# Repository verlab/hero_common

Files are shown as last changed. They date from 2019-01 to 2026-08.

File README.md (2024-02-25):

# HeRo: An Open Platform for Robotics Research and Education
<p align="justify">
Welcome to the HeRo project! This initiative introduces an innovative platform tailored for swarm robotics applications. It boasts affordability, ease of assembly using readily available components, and seamless integration with the industry-standard ROS (Robot Operating System). Our robotic platform is fully open-source, featuring a 3D-printed body coupled with open-source software. Within this repository, you'll discover a comprehensive range of ROS packages, firmware, simulations, examples, as well as additional resources such as CAD files, 3D models, schematics, and more.
</p>

For more in-depth information, please visit our documentation page [here](https://verlab.github.io/hero_common/).

<p align="center">
gif
</p>

## Authors
Paulo Rezeck (https://rezeck.github.io/)
Hector Azpurua (https://github.com/h3ct0r)
Maurício Ferrari (https://github.com/mauferrari)

## Contributing
We welcome and appreciate contributions from the community. If you have ideas, bug fixes, or enhancements you'd like to propose, please feel free to open an issue or submit a pull request. Together, we can make HeRo an even better platform for robotics enthusiasts and researchers.

Thank you 🙏 to all our contributors!

[vitorHoller](https://github.com/vitorHoller)
[Suptree](https://github.com/Suptree)
[CaioContiG](https://github.com/CaioContiG)

## License
<br />This work is licensed under a <a rel="license" href="http://creativecommons.org/licenses/by-nc-nd/4.0/">Creative Commons Attribution-NonCommercial-ShareALike 4.0 International License</a>.

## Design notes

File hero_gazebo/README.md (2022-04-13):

# Gazebo Simulations
We provide HeRo simulations on Gazebo.

## HeRo Wizard
We create a high-level UI interface that should help others to instantiate a gazebo environment.
Its is a simple wizard software that help select an environment and the robots. 
After selecting, and commit the object, they should appear on gazebo were we can drag them and place them wherever we want.
Finally, generate a launch file that compile this setup.

To create a environment, use this launch file:
```sh
$ roslaunch hero_gazebo gazebo_wizard.launch
```
It will open gazebo and this UI interface:

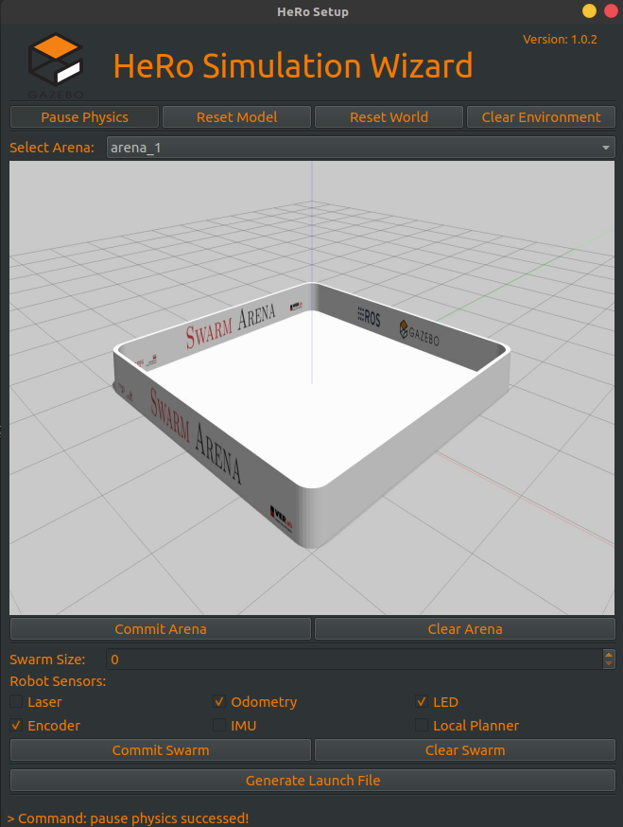
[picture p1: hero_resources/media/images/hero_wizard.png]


### Steps:

1. Select the arena in the list (see figure);
2. By clicking on commit arena button, the object will be instantiate on gazebo. Clear arena button should remove it.
3. Select the number of robots.
4. Select the sensors available for the robots.
5. By clicking on commit swarm button, the robots will be instantiate on gazebo. Clear swarm will remove them.
6. By using gazebo simulator, make adjustments on the scene, and using the Generate Launch File button will compile the scene in a launch file for future uses.

To launch a pre-set environment, use this launch file:
```sh
$ roslaunch hero_gazebo env_spawn.launch
```

## Features
- Differential drive controller
- Odometry
- IMU
- IR Proximity range (simulated with laser)

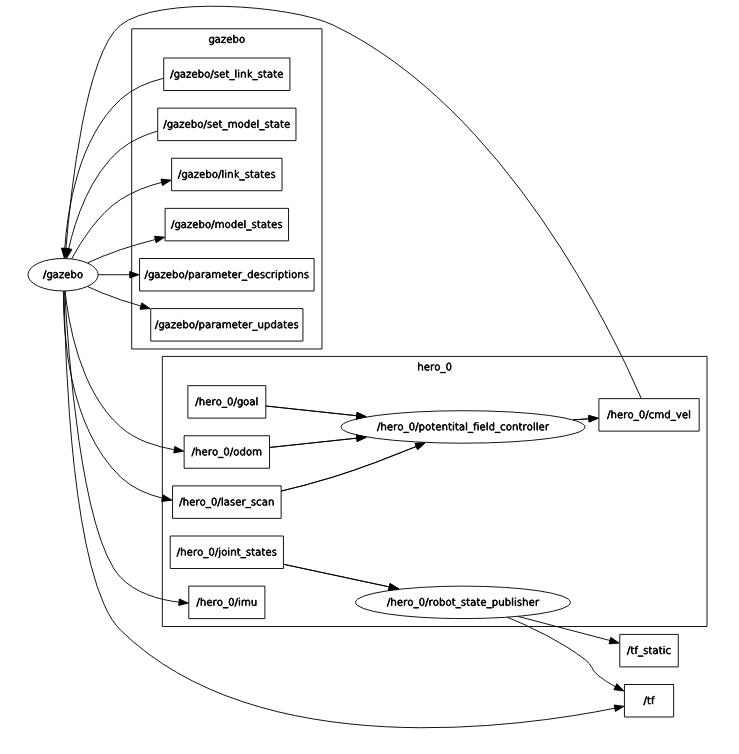
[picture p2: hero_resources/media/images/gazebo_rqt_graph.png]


## How to use
- Open the terminal and type the following command. This command will initiate Gazebo and spawn on HeRo using potential field controller as an example.
```sh
$ roslaunch hero_gazebo gazebo_bringup.launch 
```
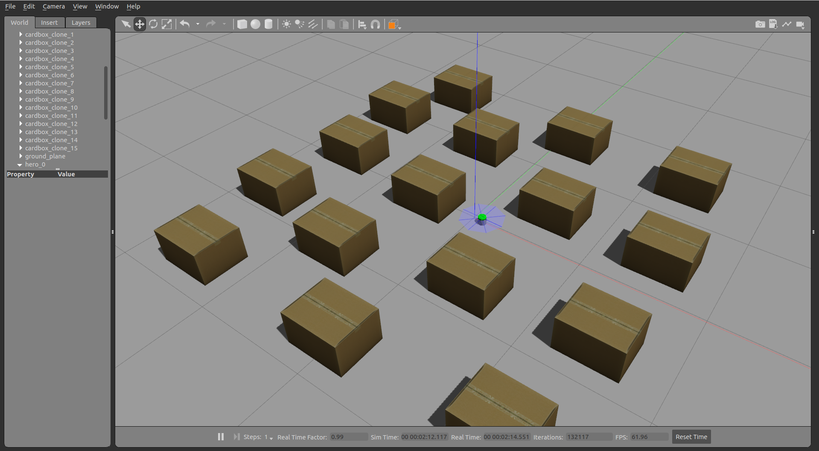
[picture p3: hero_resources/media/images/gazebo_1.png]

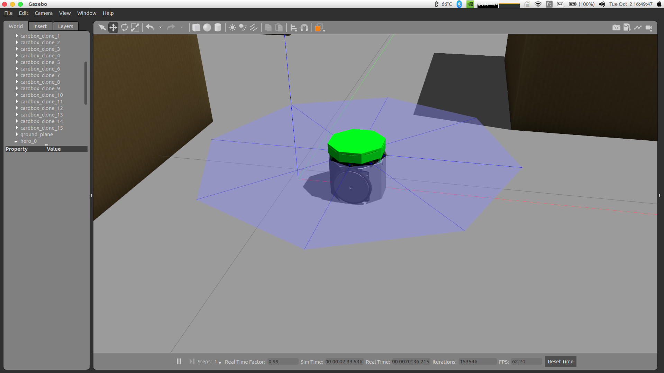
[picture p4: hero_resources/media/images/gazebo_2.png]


- If you want to spawn another robot, just use the following command. It's important set the argument id for every robot that you spawn.
```sh
$ roslaunch hero_gazebo hero_spawn.launch id:=1 y:=-0.8 x:=1.8
```
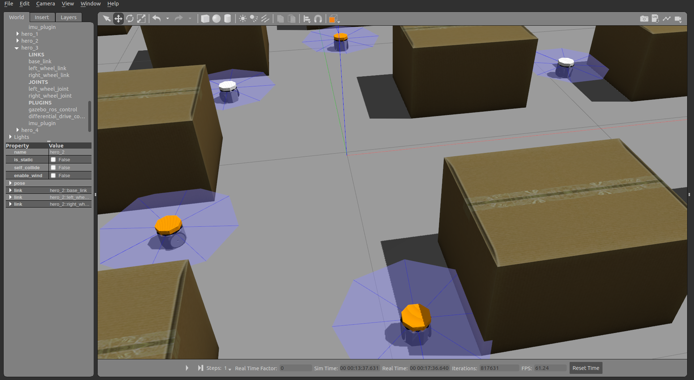
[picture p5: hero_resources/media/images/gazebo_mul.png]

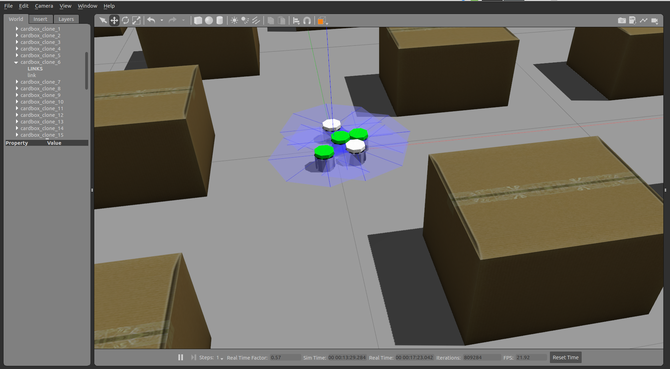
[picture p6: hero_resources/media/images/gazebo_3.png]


## Configurations
Feel free to disable some unusable sensors. I believe that the easy way to do that is commenting some includes on robot.urdf.xacro, in hero_descriptions. For example, the following hero description will disable the imu and laser.
```xml
<?xml version="1.0"?>
<robot xmlns:xacro="http://www.ros.org/wiki/xacro" name="hero_0">
  <!-- Properties  -->
  <xacro:include filename="$(find hero_description)/urdf/common.xacro" />
  <!-- Initiate HeRo model and controller -->
  <xacro:include filename="$(find hero_description)/urdf/hero.xacro" />
  <xacro:include filename="$(find hero_description)/urdf/hero.gazebo.xacro" />
  <xacro:include filename="$(find hero_description)/urdf/hero.transmissions.xacro" />
  <!-- Initiate Laser and IMU sensors -->
  <!--xacro:include filename="$(find hero_description)/urdf/laser.xacro" /-->
  <!--xacro:include filename="$(find hero_description)/urdf/laser.gazebo.xacro" /-->
  <!--xacro:include filename="$(find hero_description)/urdf/imu.gazebo.xacro" /-->

</robot>
```

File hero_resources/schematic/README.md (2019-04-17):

# HeRo: An Open Platform for Robotics Research and Education
www.verlab.dcc.ufmg.br

This project contributes to an open source ROS-based framework for swarm robotics. We propose an low cost, high availability swarm system that could be printed and assembled multiple times without special knowledge or hardware skills.
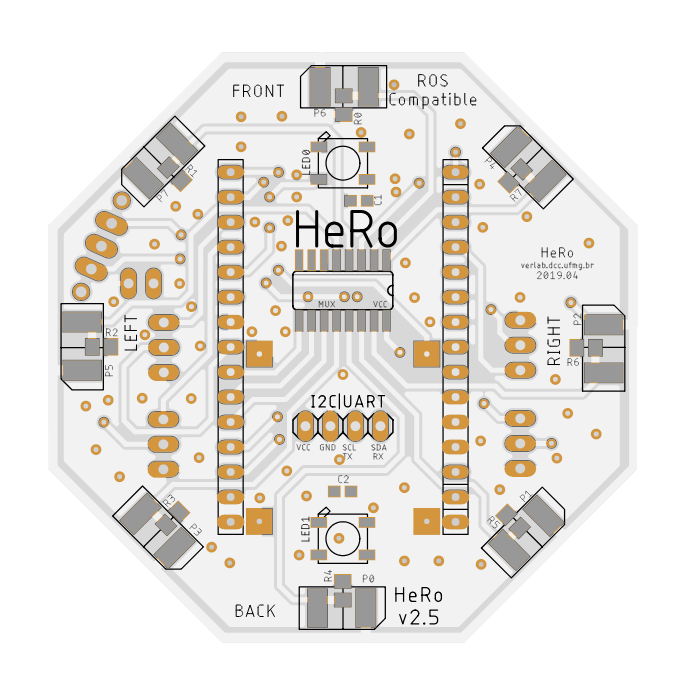
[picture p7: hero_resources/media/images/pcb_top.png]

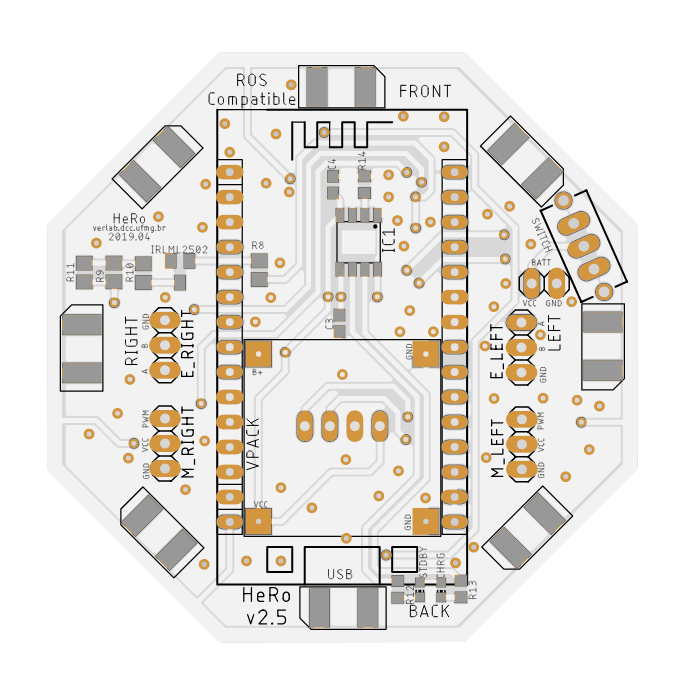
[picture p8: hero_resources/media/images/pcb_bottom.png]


# Authors:
- [Paulo Rezeck](https://github.com/rezeck)
- [Maurício Ferrari](https://github.com/mauferrari)

# PCB Manufacturer

If you intend to maker the PCB by yourself, see the PCB version 2.1. These versions are simplified to make easy to developed it.

Case you intend to order the PCB from a professional manufacturer, look for the most recent version.

# Version Description

## v2.1
- Uses pinholes as vias, since it is dificult to produce vias in homemade PCB.
- Fix inconsistency 

## v2.3
- Change pinholes to vias, since we intent to order this board from PCB manufacturer.
- Fix motor conectors position

## v2.4
- Added battery charge module (TP4056)
- Update silk

## v2.5
- Change darlington-pair to mosfet

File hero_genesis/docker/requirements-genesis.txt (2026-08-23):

# Installed into /opt/genesis (Python >= 3.10) inside the ROS 1 image.
# pymeshlab has no macOS/arm64 wheel; the Linux Docker image installs the full set.
numpy<2
torch
genesis-world

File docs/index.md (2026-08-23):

---
layout: home
title: Home
---

<section class="hero wrap">
  <p class="kicker">VeRLab · Universidade Federal de Minas Gerais</p>
  <h1>A swarm robot you can print, solder, and drive in ROS.</h1>
  <p class="lede">HeRo is a small differential-drive platform for research and teaching. The body is 3D-printed, the board is open, and every robot speaks ROS 1 over Wi‑Fi — so a classroom set behaves like a real multi-robot system, not a toy.</p>
  <div class="actions">
    <a class="btn btn-primary" href="{{ '/materials/' | relative_url }}">Build a robot</a>
    <a class="btn btn-ghost" href="{{ '/robot_simulation/' | relative_url }}">Run the simulator</a>
    <a class="btn btn-ghost" href="https://github.com/verlab/hero_common">View the source</a>
  </div>
  <div class="stats">
    <div class="stat"><b>18.72&nbsp;USD</b><span>parts, 2023 paper, retail</span></div>
    <div class="stat"><b>≤3&nbsp;h</b><span>1800&nbsp;mAh, all systems on</span></div>
    <div class="stat"><b>8 IR</b><span>proximity sensors, 20&nbsp;cm</span></div>
    <div class="stat"><b>ROS 1</b><span>rosserial over TCP</span></div>
  </div>
  <div class="media-frame">
    <iframe src="https://www.youtube.com/embed/JQvuYeF24lY" title="HeRo swarm platform" allow="accelerometer; autoplay; clipboard-write; encrypted-media; gyroscope; picture-in-picture" allowfullscreen></iframe>
  </div>
</section>

<section class="section wrap">
  <h2>From empty table to swarm</h2>
  <p class="section-lead">You do not need a machine shop. Order the PCB, print the chassis, flash the ESP8266, and join the robots on a 2.4&nbsp;GHz network.</p>
  <div class="cards">
    <article class="card">
      <h3>1. Build</h3>
      <p>Buy the BOM, fabricate the latest board, print the body, and assemble the drivetrain. A printable tutorial walks through wheels, motors, and the e-hat.</p>
      <a href="{{ '/assembly/' | relative_url }}">Assembly guide →</a>
    </article>
    <article class="card">
      <h3>2. Flash</h3>
      <p>The firmware runs on an ESP8266. Cover the IR ring at boot to open the web configurator and set the robot id, Wi‑Fi, and ROS master.</p>
      <a href="{{ '/firmware/' | relative_url }}">Firmware notes →</a>
    </article>
    <article class="card">
      <h3>3. Command</h3>
      <p>Each robot appears as <code>/hero_N</code>. Drive with <code>cmd_vel</code>, read odom and the IR scan, or spawn a swarm in Gazebo or Genesis first.</p>
      <a href="{{ '/ros/' | relative_url }}">ROS interface →</a>
    </article>
  </div>
</section>

<section class="section wrap">
  <h2>What is on the robot</h2>
  <p class="section-lead">Sensors and actuators that matter for swarm experiments, without a custom ASIC or a $400 chassis.</p>
  <div class="features">
    <div class="feature"><strong>Wheel odometry</strong><span>Quadrature encoders, 288 steps/rev, onboard PID speed control.</span></div>
    <div class="feature"><strong>IR proximity ring</strong><span>Eight long-range sensors published as a LaserScan.</span></div>
    <div class="feature"><strong>Optional IMU</strong><span>MPU6050 on I2C; off by default to save cycles.</span></div>
    <div class="feature"><strong>Addressable LEDs</strong><span>WS2812 ring for status, IDs, and experiment cues.</span></div>
    <div class="feature"><strong>Onboard charging</strong><span>TP4056 path on recent PCB revisions.</span></div>
    <div class="feature"><strong>Expansion bus</strong><span>I2C, serial, and GPIO on the top hat.</span></div>
    <div class="feature"><strong>Wi‑Fi + TCP</strong><span>rosserial to the ROS master; no USB tether.</span></div>
    <div class="feature"><strong>Gazebo + Genesis</strong><span>Same <code>/hero_N</code> topics. Wizard in Gazebo; GPU swarm viewer in Genesis World.</span></div>
    <div class="feature"><strong>Open hardware</strong><span>EAGLE schematics, STL files, and ROS packages in one repo.</span></div>
  </div>
</section>

<section class="section wrap">
  <h2>Seen in the wild</h2>
  <p class="section-lead">HeRo 2.0 was written up on Wevolver and used for odometry, flocking, coverage, and cooperative transport experiments.</p>
  <div class="actions">
    <a class="btn btn-ghost" href="https://www.wevolver.com/article/hero-20-an-ultra-low-cost-3d-printed-robotics-platform-could-open-swarm-robotics-experimentation-up-to-all">Wevolver feature</a>
    <a class="btn btn-ghost" href="{{ '/news/' | relative_url }}">Watch experiments</a>
    <a class="btn btn-ghost" href="{{ '/publications/' | relative_url }}">Read the papers</a>
  </div>
</section>

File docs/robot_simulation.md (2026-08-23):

---
layout: page
title: Simulate
permalink: /robot_simulation/
section: software
lead: Step 4 of 4. Two simulators share the same /hero_N topics as the real robot. Gazebo is the ROS 1 twin with a swarm wizard. Genesis World is a GPU-friendly viewer that loads the official hero_description URDF and the Gazebo arenas.
---

You can run this step without a physical robot. Controllers written for `/hero_N/cmd_vel` (and `/hero_N/velocity_controller/cmd_vel`) work on hardware, in Gazebo, and in Genesis.

| | [Gazebo](#gazebo) | [Genesis World](#genesis-world) |
|---|---|---|
| Package | `hero_gazebo` | `hero_genesis` |
| Needs | ROS 1 + Gazebo + Qt | Python 3.10–3.13 ([Genesis World](https://github.com/Genesis-Embodied-AI/genesis-world)); ROS 1 only if you want topics |
| Best on | Linux workstation with the wizard | Linux + **NVIDIA CUDA** (CPU also works; Apple Metal is slower than CPU on this scene) |
| Model | `hero_description` | same URDF / meshes; LED paints only `hat_link` |
| Arena | wizard worlds | `hero_gazebo/worlds/models/arena_0` … `arena_7` |

## Gazebo

### 1. Place an arena and a swarm

```sh
$ roslaunch hero_gazebo gazebo_wizard.launch
```

Gazebo opens with this wizard:

HeRo wizard

1. Select an arena and click **Commit arena**. **Clear arena** removes it.
2. Choose how many robots and which sensors they carry.
3. Click **Commit swarm**. **Clear swarm** removes them.
4. Nudge poses in Gazebo if you want, then **Generate Launch File** to save the scene.

Wizard sensors

Close Gazebo and the wizard when the launch file is written.

### 2. Replay the scene

Start Gazebo, then spawn the saved arena and robots:

```sh
$ roslaunch hero_gazebo gazebo_bringup.launch
$ roslaunch hero_gazebo env_spawn.launch
```

```sh
$ rostopic list
/hero_0/cmd_vel
/hero_0/laser
/hero_0/led
/hero_0/odom
/tf
```

Gazebo swarm

<iframe width="560" height="315" src="https://www.youtube.com/embed/IO7FPEwkZkE" title="HeRo Gazebo" frameborder="0" allow="accelerometer; autoplay; clipboard-write; encrypted-media; gyroscope; picture-in-picture" allowfullscreen></iframe>

The model includes a differential-drive controller, odometry, IMU, and IR proximity (simulated as a laser).

## Genesis World

[`hero_genesis`](https://github.com/verlab/hero_common/tree/master/hero_genesis) drives a swarm in [Genesis World](https://genesis-world.readthedocs.io/). Default mode is **kinematic** (unicycle `cmd_vel`, body-cylinder collision, no gravity). Pass `--physics` only if you want wheel contacts and gravity.

The engine speaks JSON over TCP `127.0.0.1:11312`. ROS 1 is optional: `hero_genesis_node.py` republishes the same topics as Gazebo.

### 1. Install (CPU or GPU)

Python **3.10–3.13**. Create a venv at the repo root (the `.venv/` folder is gitignored):

```sh
$ cd hero_common
$ python3 -m venv hero_genesis/.venv
$ source hero_genesis/.venv/bin/activate
$ pip install -U pip
```

Install **PyTorch first**, then Genesis. Pick the wheel that matches the machine — see [pytorch.org](https://pytorch.org/get-started/locally/) if your CUDA version differs.

```sh
# CPU (Linux / Windows / smoke test)
$ pip install torch --index-url https://download.pytorch.org/whl/cpu

# NVIDIA GPU, CUDA 12.6 (typical current driver stack)
$ pip install torch --index-url https://download.pytorch.org/whl/cu126

# Apple Silicon (Metal). For this 20-robot viewer, --backend cpu is usually faster.
$ pip install torch
```

```sh
$ pip install "git+https://github.com/Genesis-Embodied-AI/genesis-world.git"
```

`hero_genesis/requirements.txt` is the same two pins.

### 2. Run the viewer

From the repository root, with the venv active:

```sh
$ python hero_genesis/scripts/genesis_engine.py \
    --vis --num-robots 20 --arena 0 --pattern circle --backend cpu --no-physics
```

Or `hero_genesis/scripts/run_local.sh` (defaults to CPU). In another terminal, the circle-line demo talks to the engine socket:

```sh
$ python hero_genesis/scripts/circle_line_demo.py --radius 1.05 --omega 0.32
```

Close the Genesis window to stop the engine.

Useful flags:

| Flag | Meaning |
|---|---|
| `--backend cpu` / `gpu` / `cuda` / `metal` / `auto` | Device. `auto` uses CUDA when `torch.cuda.is_available()`, else CPU. |
| `--arena 0` … `7` | Same meshes as the Gazebo wizard. |
| `--model hero_light` | URDF in `hero_description/robot/` (`hero`, `hero_laser`, `hero_imu`). |
| `--no-physics` | Kinematic unicycle (default for the demo). |
| `--physics` | Wheel velocities + gravity (slower, robots can tip). |
| `--no-vis` | Headless. |

### 3. NVIDIA GPU (Linux)

Genesis is fastest on **Linux + CUDA**. The GPU path is PyTorch CUDA, then `--backend gpu`.

1. Install a current [NVIDIA driver](https://www.nvidia.com/Download/index.aspx). Check it:

```sh
$ nvidia-smi
```

You want a listed GPU and a CUDA version (driver 525+ / CUDA 12.x is the usual match for the `cu126` wheel).

2. Install CUDA-enabled PyTorch **in the venv** (do not mix a CPU wheel with `--backend gpu`):

```sh
$ source hero_genesis/.venv/bin/activate
$ pip uninstall -y torch
$ pip install torch --index-url https://download.pytorch.org/whl/cu126
$ python -c "import torch; print(torch.cuda.is_available(), torch.cuda.get_device_name(0))"
```

That must print `True` and the card name. If it prints `False`, Genesis will fall back to CPU — fix the wheel / driver before continuing.

3. Install the NVIDIA GL / EGL libraries so the interactive viewer is not silently using Mesa:

```sh
$ sudo apt update
$ sudo apt install -y libnvidia-gl-525
$ ldconfig -p | grep EGL
```

You want `libEGL_nvidia.so.0`. If the window is extremely slow, see the [Genesis EGL notes](https://genesis-world.readthedocs.io/en/latest/user_guide/overview/installation.html).

4. Launch on the GPU:

```sh
$ python hero_genesis/scripts/genesis_engine.py \
    --vis --num-robots 20 --arena 0 --pattern circle --backend gpu --no-physics
```

`gpu` and `cuda` are the same on Linux. Confirm the log line `gs.init(backend=...)` shows the CUDA backend, not `gs.cpu`.

### 4. Docker with an NVIDIA GPU

Install Docker and the [NVIDIA Container Toolkit](https://docs.nvidia.com/datacenter/cloud-native/container-toolkit/install-guide.html), then:

```sh
$ nvidia-smi
$ docker run --rm --gpus all nvidia/cuda:12.6.0-base-ubuntu22.04 nvidia-smi
```

The second command must see the same GPU. Build the Genesis image with a **CUDA** PyTorch wheel (the default image is CPU):

```sh
$ cd hero_genesis
$ docker compose --profile gpu build \
    --build-arg TORCH_INDEX=https://download.pytorch.org/whl/cu126
$ xhost +local:docker
$ docker compose --profile gpu up
```

That starts the viewer with `--backend gpu`. Environment the container needs:

```
NVIDIA_VISIBLE_DEVICES=all
NVIDIA_DRIVER_CAPABILITIES=all
```

On **WSL2**, if the window is black, pass the WSL CUDA libs as in the [Genesis Docker note](https://genesis-world.readthedocs.io/en/latest/user_guide/overview/installation.html):

```sh
$ docker run --gpus all --rm \
    -e DISPLAY=$DISPLAY \
    -e NVIDIA_DRIVER_CAPABILITIES=all \
    -e LD_LIBRARY_PATH=/usr/lib/wsl/lib \
    -v /tmp/.X11-unix:/tmp/.X11-unix \
    hero_common:genesis \
    python /hero/hero_genesis/scripts/genesis_engine.py --vis --num-robots 20 --backend gpu --no-physics
```

CPU-only Docker (no NVIDIA toolkit):

```sh
$ cd hero_genesis
$ docker compose up --build
```

The image copies `hero_description` and `hero_gazebo` so the URDF and arenas resolve inside the container.

### 5. ROS 1 topics from Genesis

On a Noetic (or Melodic) workspace that already contains this repo:

```sh
$ cd ~/catkin_ws
$ catkin_make
$ source devel/setup.bash
$ roslaunch hero_genesis genesis_bringup.launch num_robots:=20 arena:=0 backend:=gpu
```

`backend:=cpu` if you have no NVIDIA card. `hero_genesis_node.py` then publishes `/hero_N/cmd_vel`, `odom`, `laser`, `imu`, `led`, and `encoder`. Drive with the same teleop as hardware:

```sh
$ roslaunch hero_bringup hero_teleop.launch id:=0
```

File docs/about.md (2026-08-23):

---
layout: page
title: About
permalink: /about/
lead: HeRo is an open swarm-robotics platform from the Computer Vision and Robotics Lab (VeRLab) at UFMG.
---

HeRo started as a way to put a real multi-robot testbed on a student budget: a printable chassis, a board you can order from any PCB house, and software that already speaks ROS.

The current generation is **HeRo 2.0**. Firmware runs on an ESP8266, robots join the lab network over Wi‑Fi, and the same stack drives both hardware and Gazebo.

## People

- [Paulo Rezeck](https://rezeck.github.io/)
- [Héctor Azpúruá](https://github.com/h3ct0r)
- [Maurício Ferrari](https://github.com/mauferrari)
- Luiz Chaimowicz

Contributors from the community are listed on the [repository](https://github.com/verlab/hero_common).

## Lab

[VeRLab](https://www.verlab.dcc.ufmg.br/) — Departamento de Ciência da Computação, Universidade Federal de Minas Gerais, Brazil.

Contact: [rezeck@dcc.ufmg.br](mailto:rezeck@dcc.ufmg.br)

## License

Hardware documentation and this site are released under [CC BY-NC-SA 4.0](http://creativecommons.org/licenses/by-nc-sa/4.0/). Use HeRo for research and teaching; ask before a commercial run.

HeRo robots

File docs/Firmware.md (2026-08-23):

---
layout: page
title: Flash firmware
permalink: /firmware/
section: software
lead: Step 2 of 4. The sketch lives in hero_firmware/firmware and targets the ESP8266. You need the Arduino IDE (or PlatformIO) and the Silicon Labs USB-UART driver.
---

## 1. Arduino and USB driver

Install the latest Arduino IDE from the [Arduino website](https://www.arduino.cc/en/Main/Software).

The USB-UART chip needs the [Silicon Labs VCP driver](https://www.silabs.com/products/development-tools/software/usb-to-uart-bridge-vcp-drivers) for your OS. Linux often already has it.

## 2. ESP8266 board package

Open **File → Preferences**.

- Set the sketchbook location to the firmware folder in this repo.
- Add this URL to **Additional Boards Manager URLs**: `http://arduino.esp8266.com/stable/package_esp8266com_index.json`
- Restart the IDE.

Arduino preferences

Then **Tools → Boards → Boards Manager**, install **esp8266** version **2.5.0**.

Boards Manager

Select **NodeMCU 1.0** and match the other Tools settings in this screenshot.

Board settings

## 3. Upload the sketch

Open the robot sketch from the sketchbook.

Open sketch

Static defaults live in `config.h` (Wi‑Fi, ROS master, robot id). Prefer the web configurator in the next step for network name and robot id — do not bake those into the sketch unless you have to.

config.h

Connect HeRo over USB and upload.

Upload

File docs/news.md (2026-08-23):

---
layout: page
title: Experiments
permalink: /news/
lead: Odometry, cooperative transport, flocking, mapping, and coverage.
---

<div class="carousel" data-carousel>
  <div class="carousel-stage">
    <article class="carousel-slide is-active">
      <h3>Odometry</h3>
      
    </article>
    <article class="carousel-slide">
      <h3>Cooperative transportation</h3>
      
    </article>
    <article class="carousel-slide">
      <h3>Flocking</h3>
      
    </article>
    <article class="carousel-slide">
      <h3>gmapping</h3>
      
    </article>
    <article class="carousel-slide">
      <h3>Decentralized coverage</h3>
      
    </article>
  </div>
  <div class="carousel-bar">
    <button type="button" class="carousel-btn" data-prev aria-label="Previous">←</button>
    
    <button type="button" class="carousel-btn" data-next aria-label="Next">→</button>
  </div>
</div>
<script src="{{ '/assets/js/carousel.js' | relative_url }}"></script>

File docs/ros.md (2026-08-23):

---
layout: page
title: Connect a robot
permalink: /ros/
section: software
lead: Step 3 of 4. Each robot joins your 2.4 GHz network and talks to the ROS master over TCP. Set the SSID, the master IP, and a unique id — then it appears as /hero_N.
---

## 1. 2.4 GHz network

The computer that runs `roscore` is the ROS master. The robot needs that IP (port 11411 by default). A laptop hotspot or a lab router both work. HeRo Wi‑Fi is 2.4 GHz only.

## 2. Open the web configurator

The firmware has two modes: **config** (access-point + web page) and **ROS**. Start the robot in config mode.

Turn HeRo on with all IR sensors covered. The RGB LED flashes pink.

Config mode

The robot becomes a Wi‑Fi access point. Connect from a laptop or phone:

- ESSID: `HERO_ROBOT_*****`
- Password: `s3cr3tp4ss`

Access point

Open [http://192.168.4.1/](http://192.168.4.1/) and set the network the robot should join, the ROS master IP, and the robot id.

Configurator

Wi‑Fi fields

Save

Save, then power the robot off.

## 3. Start the ROS master

After the credentials are saved, the robot joins that network on the next boot. A 2-second blue blink means it connected; red means it did not.

Connection blink

You only need to configure it again if the Wi‑Fi or master IP changes. Keep the access point up whenever you use the robots.

Start the TCP rosserial server and leave it running:

```sh
$ roslaunch hero_bringup hero_bringup.launch
```

Turn the robots on. You should see connection messages like this.

Bringup

## 4. Topics and services

```sh
$ rostopic list
/hero_0/cmd_motor
/hero_0/encoder
/hero_0/imu
/hero_0/laser
/hero_0/led
/hero_0/odom
/hero_0/position_controller/cmd_vel
/hero_0/velocity_controller/cmd_vel
/tf
```

```sh
$ rosservice list
/hero_0/pid_calibration
/hero_0/set_frequency
/hero_0/set_odom
/hero_0/set_pid_parameters
```

Drive one robot from another terminal (set the id):

```sh
$ roslaunch hero_bringup hero_teleop.launch id:=0
```

Teleop

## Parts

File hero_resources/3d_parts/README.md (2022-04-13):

# 3D Printer Instructions

The parts that make up the robot were designed so that they can be printed by any conventional 3D printer. Some parts require a little more care when printing to avoid small warps, which may impact the robot's mechanics. Therefore, I recommend configuring your printer so that it can print the following parts in the following settings.

**NOTE**: Although getting good results when printing small parts (such as gears) using a 0.4m nozzle. I recommend, if possible, using a thinner nozzle to achieve even more satisfactory results.

## 3D Printer Setup
```
3D Printer: AnetA8
Nozzle: 0.4 mm
Filament: PLA
Slicer: Ultimaker Cura v4.8.0
```

## Parts
### AA8_chassis_a.gcode  
```
Profile: 0.20
Infill: 20%
Support: Yes
```      
### AA8_chasis_b.gcode
```
Profile: 0.20
Infill: 20%
Support: No
```    
### AA8_wheel.gcode
```
Profile: 0.20
Infill: 20%
Support: Yes
```
### AA8_castor_wheel.gcode     
```
Profile: 0.20
Infill: 100%
Support: No
```
### AA8_motor_gear.gcode
```
Profile: 0.20
Infill: 100%
Support: No
```
### AA8_motor_glove.gcode
```
Profile: 0.20
Infill: 100%
Support: No
```
### AA8_encoder_gear.gcode
```
Profile: 0.20
Infill: 100%
Support: No
```
### AA8_chasis_b_adjust.gcode  
**NOTE**: This is a tweaking piece. Its purpose is to adjust the height of the gear encoder in relation to the wheel gear. Print this part at different heights, for example (0.1, 0.2, 0.3, 0.4 mm) and test which provides the best fit between the gear encoder and the wheel.
```
Profile: 0.10
Infill: 100%
Support: No
```
### AA8_cover.gcode
```
Profile: 0.20
Infill: 20%
Support: Yes
```
### AA8_ehat.gcode          
```
Profile: 0.20
Infill: 20%
Support: No
```
### AA8_ehat_glove.gcode  
```
Profile: 0.20
Infill: 100%
Support: No
```

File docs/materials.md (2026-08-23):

---
layout: page
title: Parts and cost
permalink: /materials/
section: build
lead: 18.72 USD in parts (Rezeck et al., Autonomous Robots, 2023). Retail, one-off buys at the time of the paper.
---

<p class="step-meta">Tutorial v1.0 · 27 Sep 2025 · Paulo Rezeck</p>

## Specifications (paper)

| Specification | Value |
|---|---|
| Size (L × W × H) | 0.068 × 0.073 × 0.076 m |
| Weight | 0.156 kg |
| Wheel distance | 0.0631 m |
| Wheel diameter | 0.0492 m |
| Linear speed | 0.25 m/s |
| Inertia | Ixx = Iyy = 1.27×10⁻⁴ kg·m², Izz = 1.04×10⁻⁴ kg·m² |
| Battery | 3.7 V, 1800 mAh Li-Po |
| Autonomy | up to 3 hours with all components in continuous use |
| MCU | ESP8266, 32-bit 160 MHz, 4 MB, Wi-Fi 802.11 |
| IR ring | 8 × TCRT5000, 45°, pulsed over-current, range up to 20 cm |
| Encoder | Kailh / mouse rotary, 48 PPR; 1:6 wheel–encoder gear → 1.25° / 0.54 mm per step |
| Motors | 2 × SG90 continuous servos, 1.8 kgf·cm |

<figure class="figure">
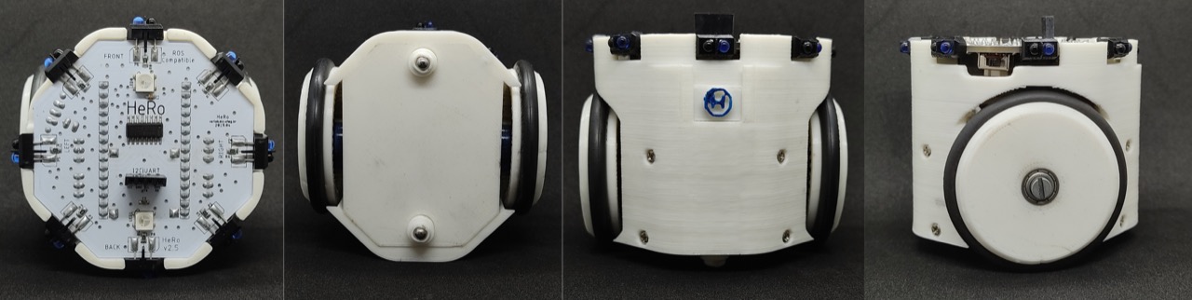
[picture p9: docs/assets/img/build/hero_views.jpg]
HeRo from top, bottom, front, and side
  
  <figcaption>HeRo 2.0, from the 2023 Autonomous Robots paper (Fig. “Top, bottom, front, and left views”).</figcaption>
</figure>

## Cost per robot (paper)

| Parts | Qty | Cost (USD) |
|---|---:|---:|
| Servo motors SG-90 | 2 | 2.06 |
| Mouse encoder 48 PPR | 2 | 0.10 |
| ESP8266 NodeMCU | 1 | 2.50 |
| Rubber O-ring 38 mm | 2 | 0.10 |
| IR TCRT5000 | 8 | 0.68 |
| LED RGB WS2812b | 2 | 0.51 |
| IMU MPU6050 | 1 | 0.85 |
| Li-Po 3.7 V 1800 mAh | 1 | 5.85 |
| PCB board and components | 1 | 4.30 |
| 3D-printed PLA parts and fasteners | 1 | 1.50 |
| **Total** |  | **18.72** |

## What to buy (assembly checklist)

From the build tutorial (September 2025). Use this on the bench; the paper table above is the cost reference.

**Drive and locomotion**
- SG90 continuous-rotation servos ×2 (green-label variant recommended), with horns and screws
- O-ring tires ×2
- 623ZZ bearings ×2
- Steel balls 4 mm ×2 (casters)
- M2.5 self-tapping screws plus assorted M3 screws, nuts, and washers

**Electronics**
- Blank HeRo v2 PCB (see [Order the PCB]({{ '/pcb_order/' | relative_url }}))
- ESP8266 / NodeMCU
- Li-Po 103450 (1S, 3.7 V 1800 mAh)
- MPU6050 IMU (optional e-hat)
- Two mouse-style quadrature encoders
- Passives and ICs listed on the [solder page]({{ '/pcb_assembly/' | relative_url }})

**Print set** — chassis A/B, wheels, casters, cover, USB slider, e-hat, gloves, motor gears, motor shafts, encoder shafts. See [Print the body]({{ '/printing/' | relative_url }}).

A printable spreadsheet is still in the repo: [assembly_materials.pdf](https://github.com/verlab/hero_common/raw/master/hero_resources/assembly_materials.pdf).

## Tools

Phillips and flat-head screwdrivers, needle-nose pliers, diagonal cutters, wire strippers, precision knife, fine-tip soldering iron, flux, desoldering braid, multimeter, ESD tweezers, safety glasses, isopropyl alcohol. Optional: current-limited bench PSU, hot-air station, PCB vise.

<p><a class="btn btn-primary" href="{{ '/pcb_order/' | relative_url }}">Next: order the PCB</a></p>

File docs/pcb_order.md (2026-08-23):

---
layout: page
title: Order the PCB
permalink: /pcb_order/
section: build
lead: Gerbers live under hero_resources/schematic. Homemade boards: v2.1. A fab house: latest in the repo is v2.7. The paper used a white soldermask so the LEDs read better — that is a preference, not a rule.
---
<style>
.column {
  float: left;
  width: 50.0%;
  padding: 5px;
  box-sizing: border-box;
}

/* Clearfix (clear floats) */
.row::after {
  content: "";
  clear: both;
  display: table;
}
</style>

<h3>How to request a PCB manufacturing service?</h3>

<p align="justify">Today it is extremely easy and affordable to prototype PCBs. The following is a tutorial on how you can request a PCB manufacturing service.</p>

<p align="justify">After designing the robot's PCB, we requested the services of the <a href="https://jlcpcb.com" target="_blank" rel="noopener noreferrer">JLCPCB company</a>, as it is good in quality and low cost. 
  Of course, other companies are just as good, so feel free to choose.</p>
  
<p align="justify">About the color of the PCB, we opted for the white color because it improves the brightness performance of the LEDs, but there are no restrictions on this.</p>
  
<p align="justify">Although we used some SMD components, we had no difficulty using the soldering iron to solder them. That way, a stencil board was not required.</p>

<p align="justify">To start an order, simply download the <a href="https://github.com/verlab/hero_common/blob/noetic-devel/hero_resources/schematic/EAGLE/projects/hero_v2.7/board_2023-10-08.zip" target="_blank" rel="noopener noreferrer">Gerber File</a>, and send it to the PCB manufacturing service of your choice. Just pay attention to these requirements:</p>

 <ul class="fa-ul" style="list-style: none;">
  <li> Finished Copper >= 1 oz</li>
  <li> Min Hole Size: 0.3mm</li>
  <li> Min Track/Spacing: 6/6mil</li>
 </ul>
 
 <h4>PCB view</h4>
 <div class="row">
  <div class="column">
    
  </div>
  <div class="column">
    
  </div>
</div>

<p align="justify">Here is an exemple using the JLCPCB manufacturing service.</p>



<p align="justify">After a few days we receive the PCBs and we can start assembling the components.</p>


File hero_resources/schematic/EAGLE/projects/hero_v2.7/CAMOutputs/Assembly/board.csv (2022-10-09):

Qty | Value | Device | Package | Parts | Description | POPULARITY | PROD_ID | SKU | SPICEPREFIX
2 |  | CONN_02JST-PTH-2 | JST-2-PTH | BATT0, BATT1 | Multi connection point. Often used as Generic Header-pin footprint for 0.1 inch spaced/style header connections |  | CONN-09863 | PRT-09914
1 |  | MOSFET-NREFLOW | SOT23 | IRLML2502 | N-Channel Mosfet
1 |  | MT3608 | MT3608 | MT3608
4 |  | PINHD-1X3 | 1X03 | E_LEFT, E_RIGHT, M_LEFT, M_RIGHT | PIN HEADER
1 |  | PINHD-1X4 | 1X04 | E-HAT | PIN HEADER
8 |  | TCRT5000 | TCRT5000 | P0, P1, P2, P3, P4, P5, P6, P7
2 | 0.10 nF | C-USC0603 | C0603 | C1, C2 | CAPACITOR, American symbol
1 | 0R | R-EU_R0805 | R0805 | R15 | RESISTOR, European symbol
1 | 0R | R-US_R0805 | R0805 | R9 | RESISTOR, American symbol |  |  |  | R
2 | 10 uF | C-USC0603 | C0603 | C3, C4 | CAPACITOR, American symbol
1 | 102 | R-EU_R0805 | R0805 | R13 | RESISTOR, European symbol
1 | 103 | R-EU_R0805 | R0805 | R12 | RESISTOR, European symbol
1 | 122 | R-EU_R0603 | R0603 | R14 | RESISTOR, European symbol
1 | 18R | R-US_R0805 | R0805 | R10 | RESISTOR, American symbol |  |  |  | R
1 | 4051D | 4051D | SO16 | MUX | 8-channel ANALOG MULTIPLEXER
8 | 4k7 | R-US_M0805 | M0805 | R0, R1, R2, R3, R4, R5, R6, R7 | RESISTOR, American symbol
1 | 4k7 | R-US_R0805 | R0805 | R8 | RESISTOR, American symbol |  |  |  | R
1 | ESP12E_DEVKIT | ESP12E_DEVKIT | ESP12E_DEVKIT | ESP-12E | ESP12E DEVKIT BOARD
1 | GREEN | LEDSML0805 | SML0805 | STDBY | LED
1 | NM | R-US_R0805 | R0805 | R11 | RESISTOR, American symbol |  |  |  | R
1 | RED | LEDSML0805 | SML0805 | CHRG | LED
1 | SS12F2356 | SS12F2356 | HH3T90 | SWITCH | TINY SWITCH MOM OFF MOM | 0
1 | TP4056 | TP4056 | SOP-8 | TP4056 |  |  |  |  | X
2 | WS2812B5050 | WS2812B5050 | WS2812B | LED0, LED1

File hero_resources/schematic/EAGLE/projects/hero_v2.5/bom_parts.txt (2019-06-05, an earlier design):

Partlist exported from /home/rezeck/EAGLE/projects/hero_v2.5/board.sch at 6/5/19 10:48 AM

Part      Value         Device         Package       Description                  SPICEPREFIX
BATT                    PINHD-1X2      1X02          PIN HEADER                              
C1        0.10 nF       C-USC0603      C0603         CAPACITOR, American symbol              
C2        0.10 nF       C-USC0603      C0603         CAPACITOR, American symbol              
C3        10 uF         C-USC0603      C0603         CAPACITOR, American symbol              
C4        10 uF         C-USC0603      C0603         CAPACITOR, American symbol              
CHRG                    LEDSML0805     SML0805       LED                                     
E_LEFT                  PINHD-1X3      1X03          PIN HEADER                              
E_RIGHT                 PINHD-1X3      1X03          PIN HEADER                              
I2C|UART                PINHD-1X4      1X04          PIN HEADER                              
IC1       TP4056        TP4056         SOP-8                                      X          
IC2       4051D         4051D          SO16          8-channel ANALOG MULTIPLEXER            
IRLML2502               MOSFET-NREFLOW SOT23         N-Channel Mosfet                        
LED0      WS2812B5050   WS2812B5050    WS2812B                                               
LED1      WS2812B5050   WS2812B5050    WS2812B                                               
M_LEFT                  PINHD-1X3      1X03          PIN HEADER                              
M_RIGHT                 PINHD-1X3      1X03          PIN HEADER                              
OS1                     STEPUP         STEPUP                                                
P0                      TCRT5000       TCRT5000                                              
P1                      TCRT5000       TCRT5000                                              
P2                      TCRT5000       TCRT5000                                              
P3                      TCRT5000       TCRT5000                                              
P4                      TCRT5000       TCRT5000                                              
P5                      TCRT5000       TCRT5000                                              
P6                      TCRT5000       TCRT5000                                              
P7                      TCRT5000       TCRT5000                                              
R0        4k7           R-US_M0805     M0805         RESISTOR, American symbol               
R1        4k7           R-US_M0805     M0805         RESISTOR, American symbol               
R2        4k7           R-US_M0805     M0805         RESISTOR, American symbol               
R3        4k7           R-US_M0805     M0805         RESISTOR, American symbol               
R4        4k7           R-US_M0805     M0805         RESISTOR, American symbol               
R5        4k7           R-US_M0805     M0805         RESISTOR, American symbol               
R6        4k7           R-US_M0805     M0805         RESISTOR, American symbol               
R7        4k7           R-US_M0805     M0805         RESISTOR, American symbol               
R8        4k7           R-US_R0805     R0805         RESISTOR, American symbol    R          
R9        0 R           R-US_R0805     R0805         RESISTOR, American symbol    R          
R10       18 R          R-US_R0805     R0805         RESISTOR, American symbol    R          
R11       NM            R-US_R0805     R0805         RESISTOR, American symbol    R          
R12       102           R-EU_R0805     R0805         RESISTOR, European symbol               
R13       102           R-EU_R0805     R0805         RESISTOR, European symbol               
R14       122           R-EU_R0603     R0603         RESISTOR, European symbol               
STDBY                   LEDSML0805     SML0805       LED                                     
SWITCH    TL37YO        TL37YO         TL3XYO        TINY SWITCH MOM OFF MOM                 
U$1       ESP12E_DEVKIT ESP12E_DEVKIT  ESP12E_DEVKIT ESP12E DEVKIT BOARD

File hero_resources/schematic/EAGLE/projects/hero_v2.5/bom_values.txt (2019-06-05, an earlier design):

Partlist exported from /home/rezeck/EAGLE/projects/hero_v2.5/board.sch at 6/5/19 10:48 AM

Qty Value         Device         Package       Parts                            Description                  SPICEPREFIX
2                 LEDSML0805     SML0805       CHRG, STDBY                      LED                                     
1                 MOSFET-NREFLOW SOT23         IRLML2502                        N-Channel Mosfet                        
1                 PINHD-1X2      1X02          BATT                             PIN HEADER                              
4                 PINHD-1X3      1X03          E_LEFT, E_RIGHT, M_LEFT, M_RIGHT PIN HEADER                              
1                 PINHD-1X4      1X04          I2C|UART                         PIN HEADER                              
1                 STEPUP         STEPUP        OS1                                                                      
8                 TCRT5000       TCRT5000      P0, P1, P2, P3, P4, P5, P6, P7                                           
1   0 R           R-US_R0805     R0805         R9                               RESISTOR, American symbol    R          
2   0.10 nF       C-USC0603      C0603         C1, C2                           CAPACITOR, American symbol              
2   10 uF         C-USC0603      C0603         C3, C4                           CAPACITOR, American symbol              
2   102           R-EU_R0805     R0805         R12, R13                         RESISTOR, European symbol               
1   122           R-EU_R0603     R0603         R14                              RESISTOR, European symbol               
1   18 R          R-US_R0805     R0805         R10                              RESISTOR, American symbol    R          
1   4051D         4051D          SO16          IC2                              8-channel ANALOG MULTIPLEXER            
8   4k7           R-US_M0805     M0805         R0, R1, R2, R3, R4, R5, R6, R7   RESISTOR, American symbol               
1   4k7           R-US_R0805     R0805         R8                               RESISTOR, American symbol    R          
1   ESP12E_DEVKIT ESP12E_DEVKIT  ESP12E_DEVKIT U$1                              ESP12E DEVKIT BOARD                     
1   NM            R-US_R0805     R0805         R11                              RESISTOR, American symbol    R          
1   TL37YO        TL37YO         TL3XYO        SWITCH                           TINY SWITCH MOM OFF MOM                 
1   TP4056        TP4056         SOP-8         IC1                                                           X          
2   WS2812B5050   WS2812B5050    WS2812B       LED0, LED1

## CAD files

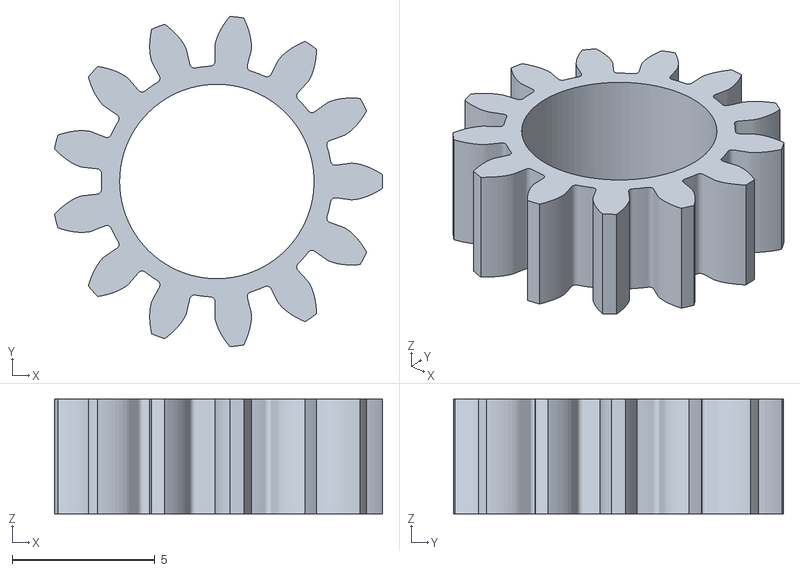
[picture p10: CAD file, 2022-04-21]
docs/assets/models/motor_gear.stl
11.5 x 11.6 x 4.02

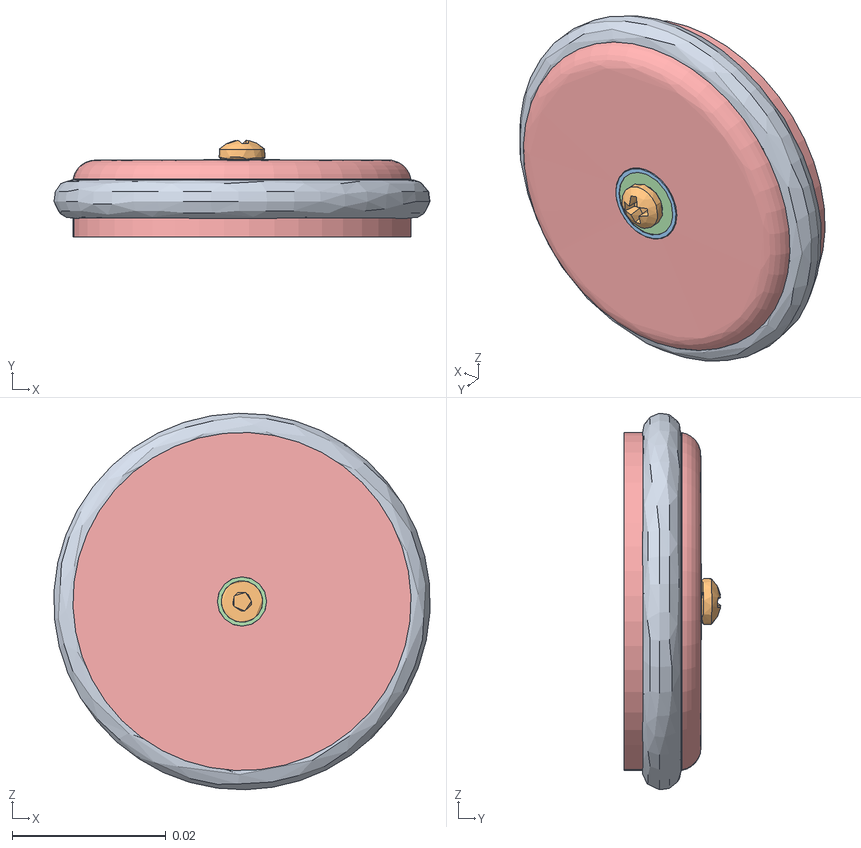
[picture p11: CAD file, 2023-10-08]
hero_description/meshes/wheel.obj
0.0489 x 0.0126 x 0.049
aa_Body2
Body1_1_Body1:1

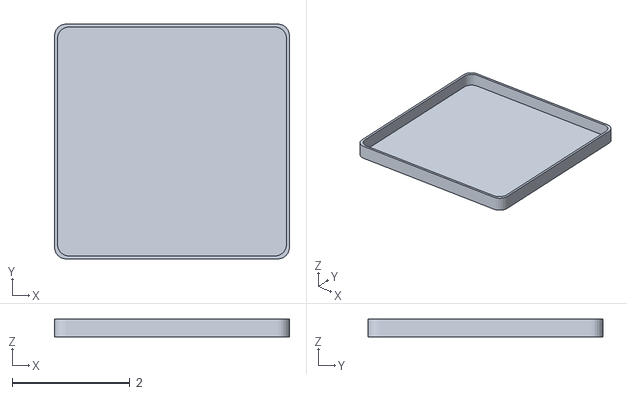
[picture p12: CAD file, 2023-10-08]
hero_gazebo/worlds/models/arena_0/arena.obj
4.00 x 4.00 x 0.3

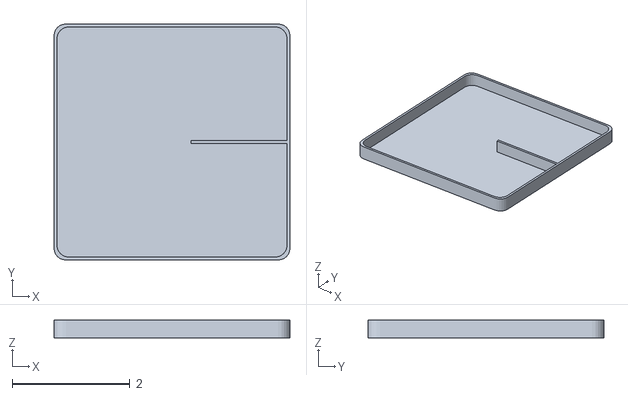
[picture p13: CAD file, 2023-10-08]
hero_gazebo/worlds/models/arena_1/arena.obj
4.00 x 4.00 x 0.3

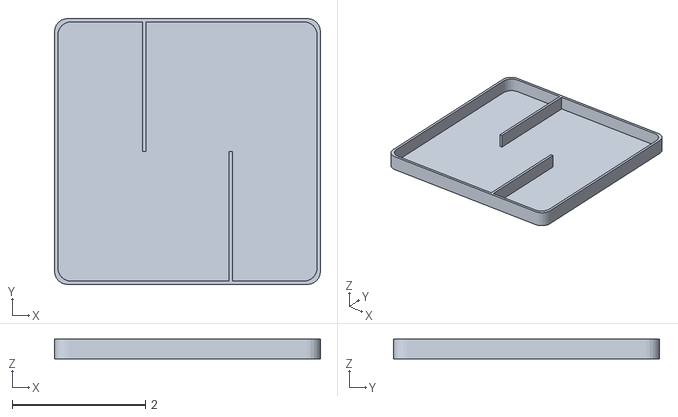
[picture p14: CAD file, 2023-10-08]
hero_gazebo/worlds/models/arena_3/arena.obj
4.00 x 4.00 x 0.3

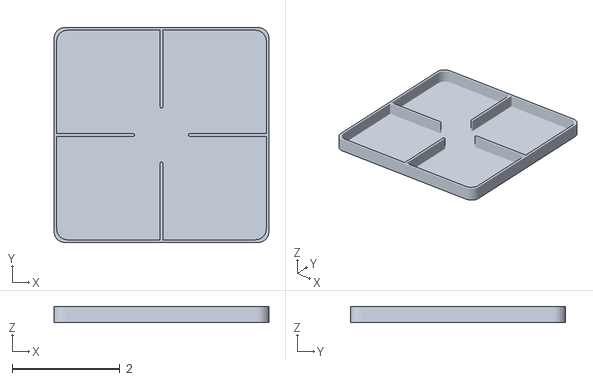
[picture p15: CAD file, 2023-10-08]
hero_gazebo/worlds/models/arena_5/arena.obj
4.00 x 4.00 x 0.3

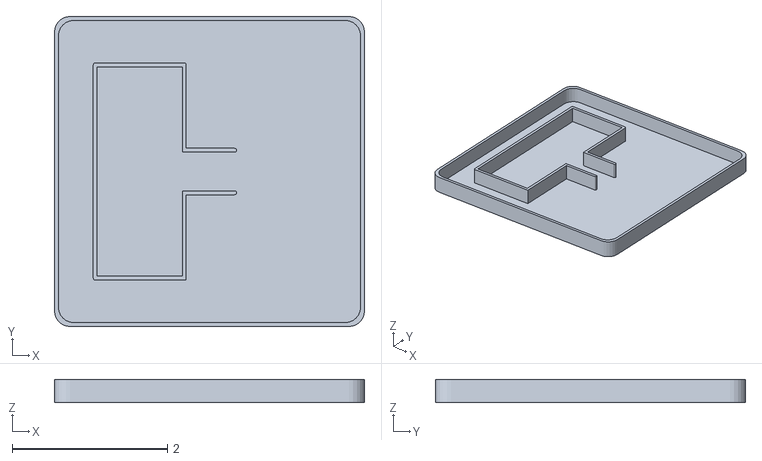
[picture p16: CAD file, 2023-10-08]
hero_gazebo/worlds/models/arena_7/arena.obj
4.00 x 4.00 x 0.3

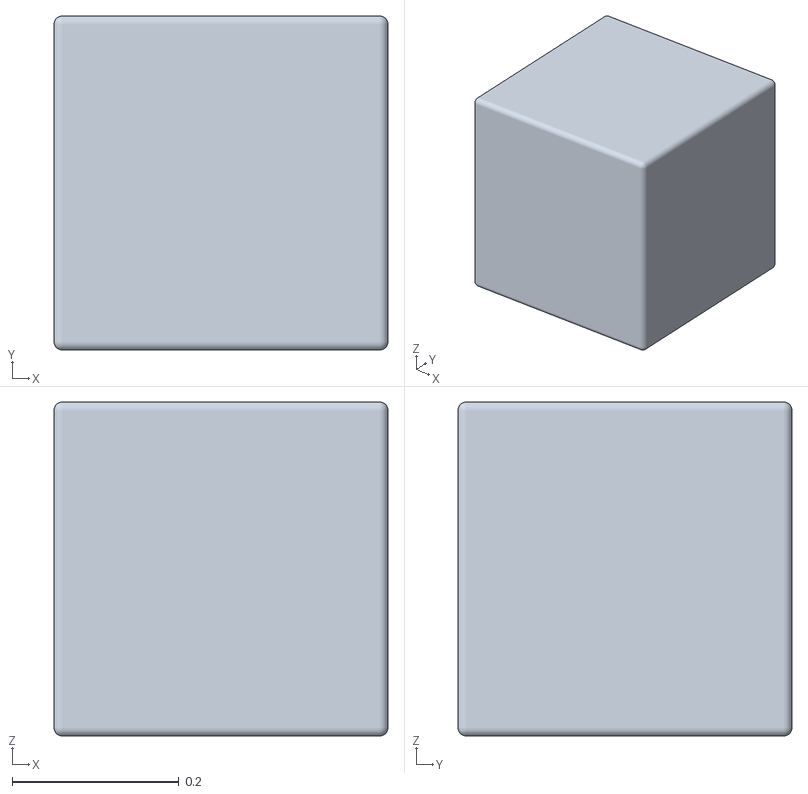
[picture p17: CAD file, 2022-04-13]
hero_gazebo/worlds/models/objects/cube/cube.stl
0.4 x 0.4 x 0.4

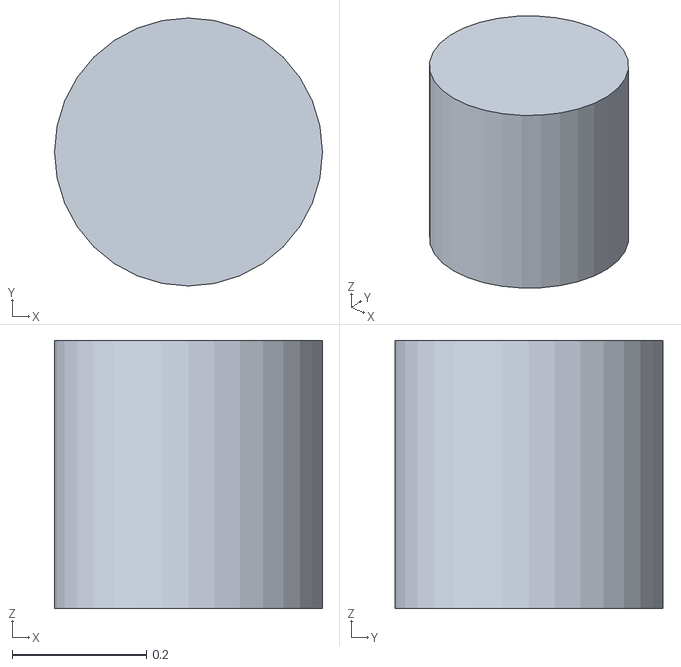
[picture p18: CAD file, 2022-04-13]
hero_gazebo/worlds/models/objects/cylinder/cylinder.stl
0.4 x 0.4 x 0.4

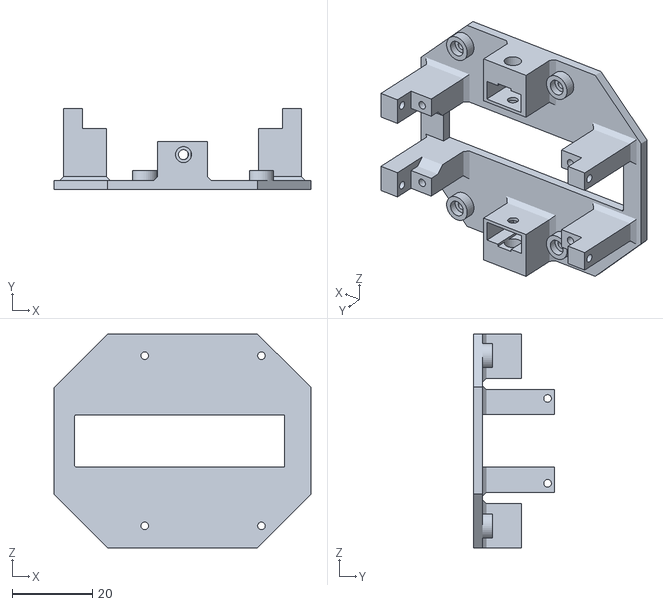
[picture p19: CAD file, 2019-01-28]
hero_resources/3d_parts/board_chassis.stl
64.0 x 20.2 x 53.2

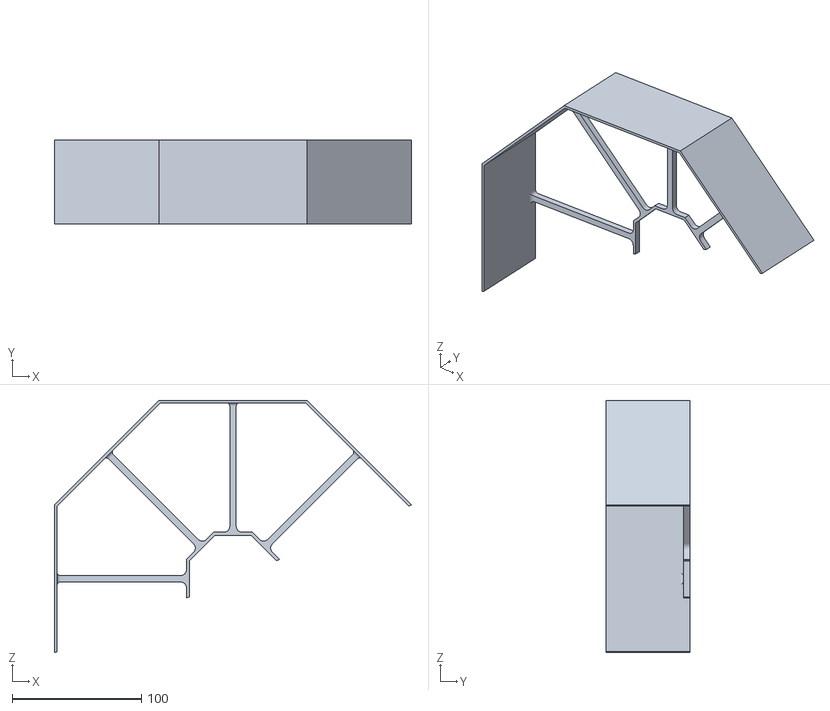
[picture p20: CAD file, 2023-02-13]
hero_resources/3d_parts/ir_calibration/ir_calibration_support.stl
276.0 x 65.0 x 195.2

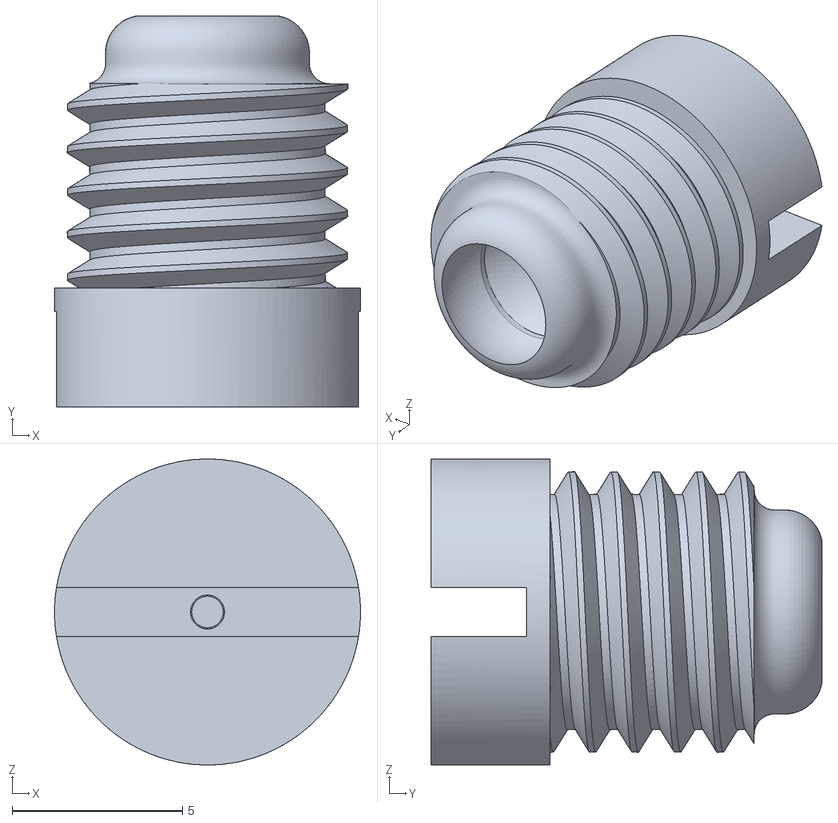
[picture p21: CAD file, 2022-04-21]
docs/assets/models/castor_wheel.stl
9.00 x 11.5 x 9.00

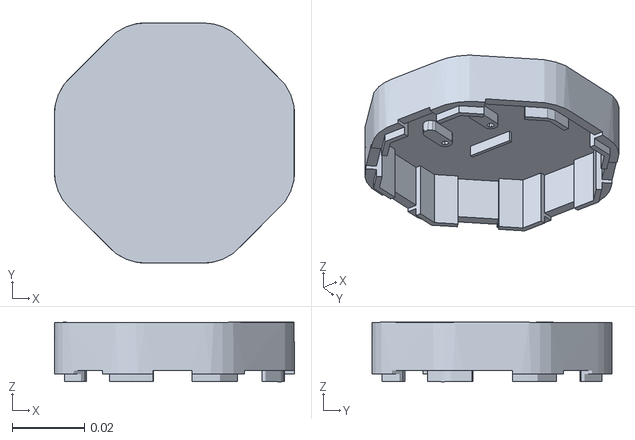
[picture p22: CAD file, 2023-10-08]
hero_description/meshes/hat.obj
0.0666 x 0.0666 x 0.0165

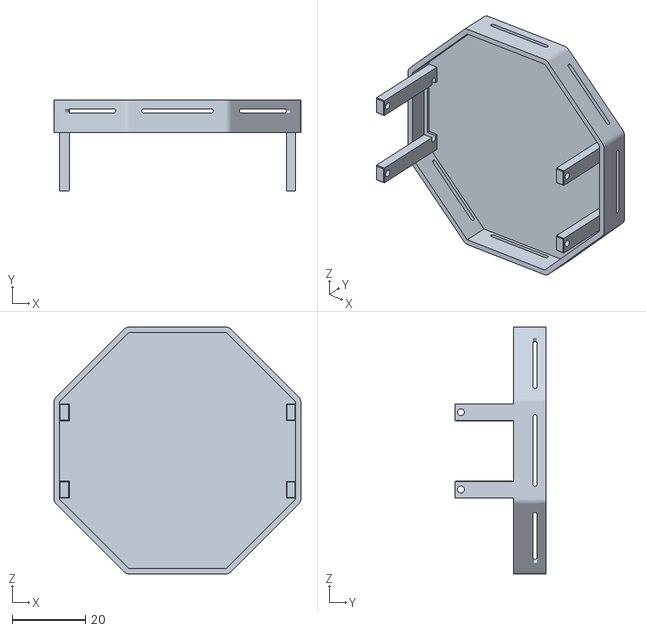
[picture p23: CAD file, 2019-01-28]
hero_resources/3d_parts/hat.stl
67.5 x 25.0 x 67.5

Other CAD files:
hero_gazebo/worlds/models/arena_2/arena.obj
hero_gazebo/worlds/models/arena_4/arena.obj
hero_gazebo/worlds/models/arena_6/arena.obj
hero_resources/3d_parts/ir_calibration/ircal_holder.stl
docs/assets/models/chasis_b.stl
docs/assets/models/chassis_a.stl
docs/assets/models/cover.stl
docs/assets/models/cover_usb.stl
docs/assets/models/ehat.stl
docs/assets/models/ehat_glove.stl
docs/assets/models/encoder_shaft.stl
docs/assets/models/motor_shaft.stl
docs/assets/models/wheel.stl
hero_description/meshes/base_link.obj
hero_description/meshes/flag.obj
hero_resources/3d_parts/deprecated/encoder_gear.stl
hero_resources/3d_parts/deprecated/motor_chassis.stl
hero_resources/3d_parts/deprecated/shell.stl
hero_resources/3d_parts/deprecated/wheel.stl
hero_resources/3d_parts/ir_calibration/ircal_plate.stl
hero_resources/3d_parts/ir_calibration/ircal_rod.stl
hero_resources/3d_parts/motor_chassis.stl
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

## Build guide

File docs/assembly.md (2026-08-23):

---
layout: page
title: Assemble the robot
permalink: /assembly/
section: build
lead: About 45 minutes of reading and 110 minutes of building (tutorial v1.0, 27 Sep 2025). Figures are from that tutorial. Geometry and encoder ratios are from Rezeck et al., Auton. Robot (2023).
---

<p class="toc"><a href="#casters">Casters</a> · <a href="#motors">Motors</a> · <a href="#wheels">Wheels</a> · <a href="#battery">Battery</a> · <a href="#encoders">Encoders</a> · <a href="#board">Board</a> · <a href="#ehat">E-hat</a> · <a href="#trouble">Troubleshooting</a></p>

[PDF of the same tutorial]({{ '/assembly/Hero V2 Robot Build Tutorial-compressed.pdf' | relative_url }})

## Casters {#casters}

Take a printed caster shell, drop in a 4 mm steel ball, and crimp the rim with pliers so the ball stays in but still turns. Screw both casters to Chassis A. Set the height so the chassis sits level.

<div class="figure-grid">
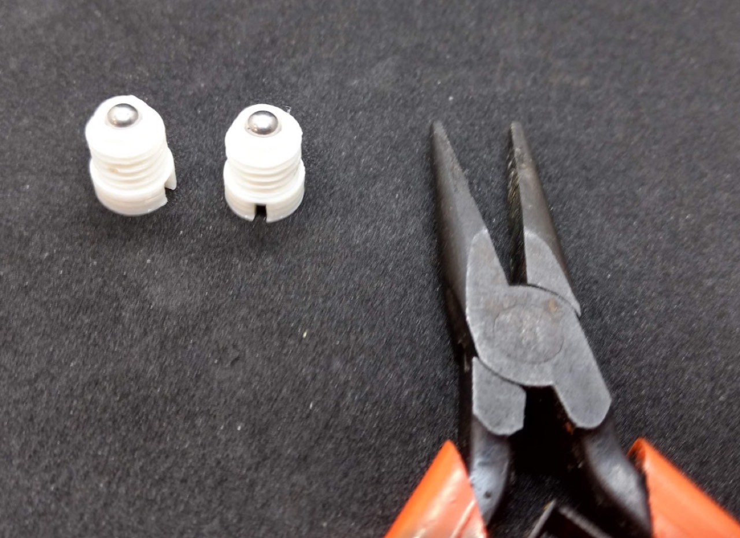
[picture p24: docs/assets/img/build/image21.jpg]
Inserting the caster ball
  <figure class="figure"><figcaption>Ball in the cup.</figcaption></figure>
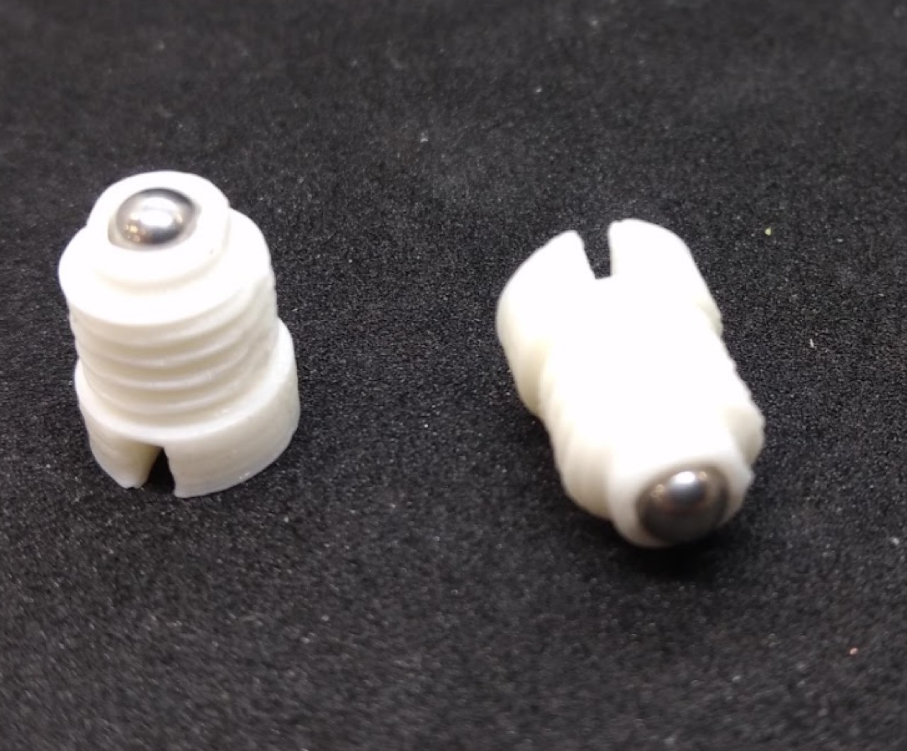
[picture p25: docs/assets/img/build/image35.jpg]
Crimping the caster
  <figure class="figure"><figcaption>Crimp just enough.</figcaption></figure>
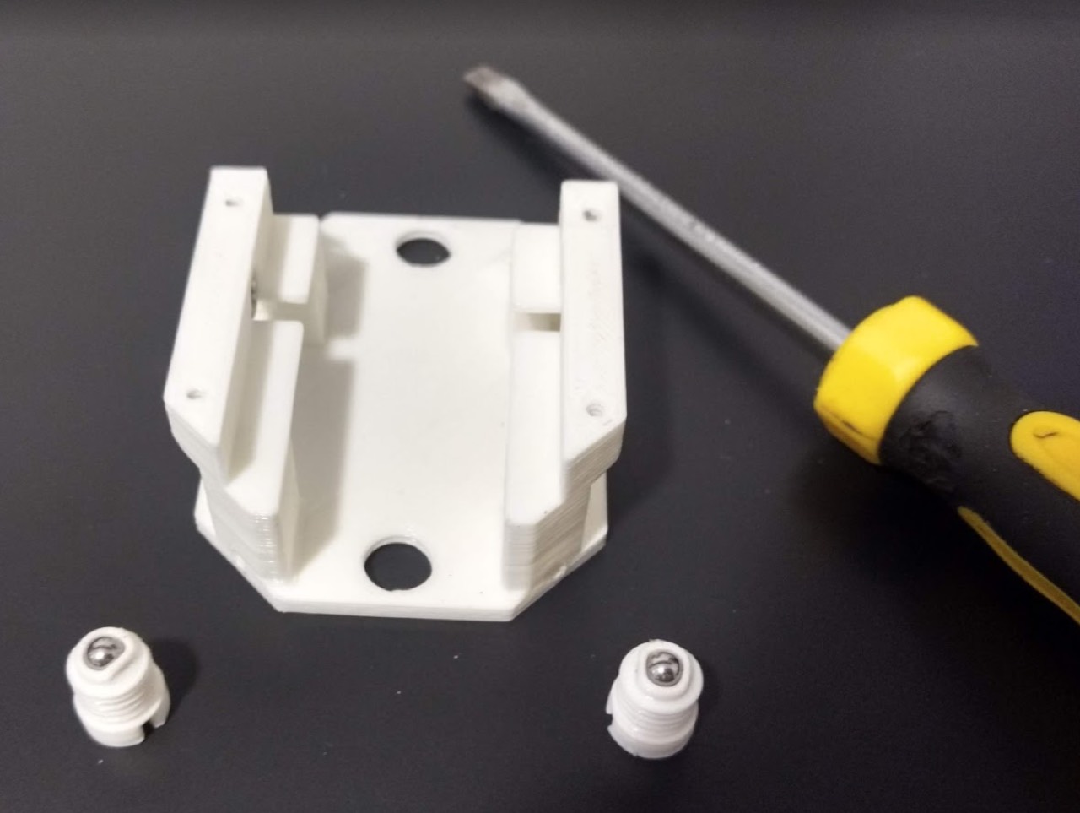
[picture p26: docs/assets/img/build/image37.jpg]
Casters on chassis A
  <figure class="figure"><figcaption>On Chassis A.</figcaption></figure>
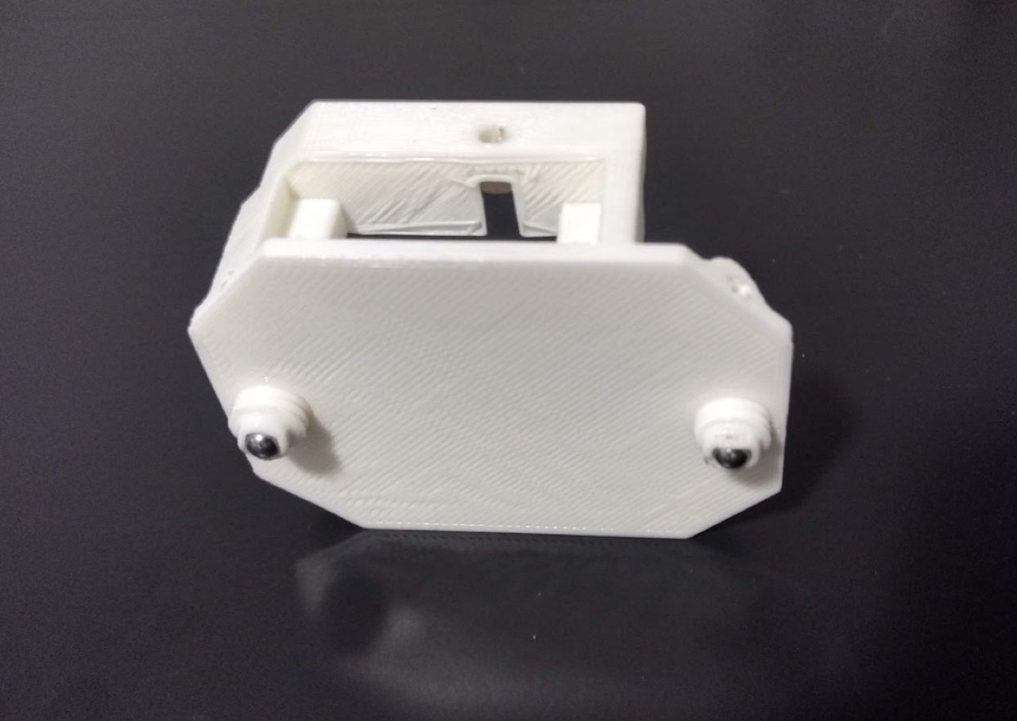
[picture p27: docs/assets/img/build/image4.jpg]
Height adjustment
  <figure class="figure"><figcaption>Adjust clearance.</figcaption></figure>
</div>

## Motors {#motors}

Prefer SG90 units already converted to continuous rotation. The tutorial recommends the **green-label** variant (no resistor swap). Stock angular servos need a CR modification first; after that, command ~1500 µs to center.

<figure class="figure">
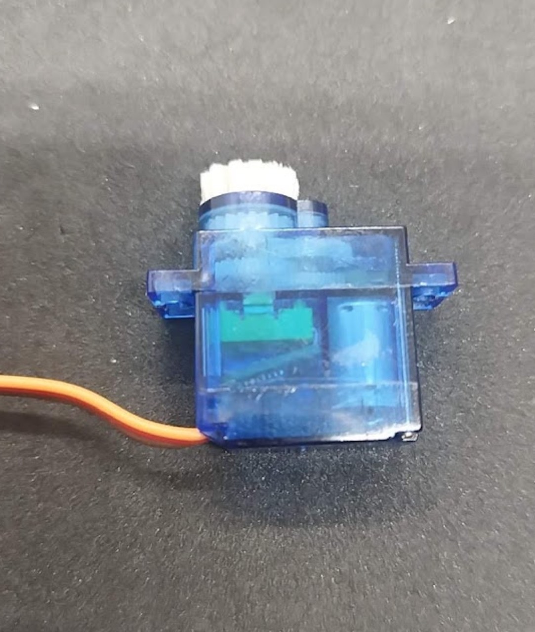
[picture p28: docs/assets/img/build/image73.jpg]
SG90 continuous servo
  
  <figcaption>SG90 ready for the printed gear.</figcaption>
</figure>

**Gear adapter**

1. Pick a stock horn that fits the printed motor gear. Cut it down to the cylindrical hub. Wear glasses — chips fly.
2. Trim the hub until it press-fits the gear. A small drop of cyanoacrylate at the interface; keep glue off the teeth.
3. If the servo shaft sticks out, shorten it ~1.00–1.20 mm, cut flat.
4. Fasten with the original horn screw. Do not overtighten — friction kills the mesh.

<div class="figure-grid">
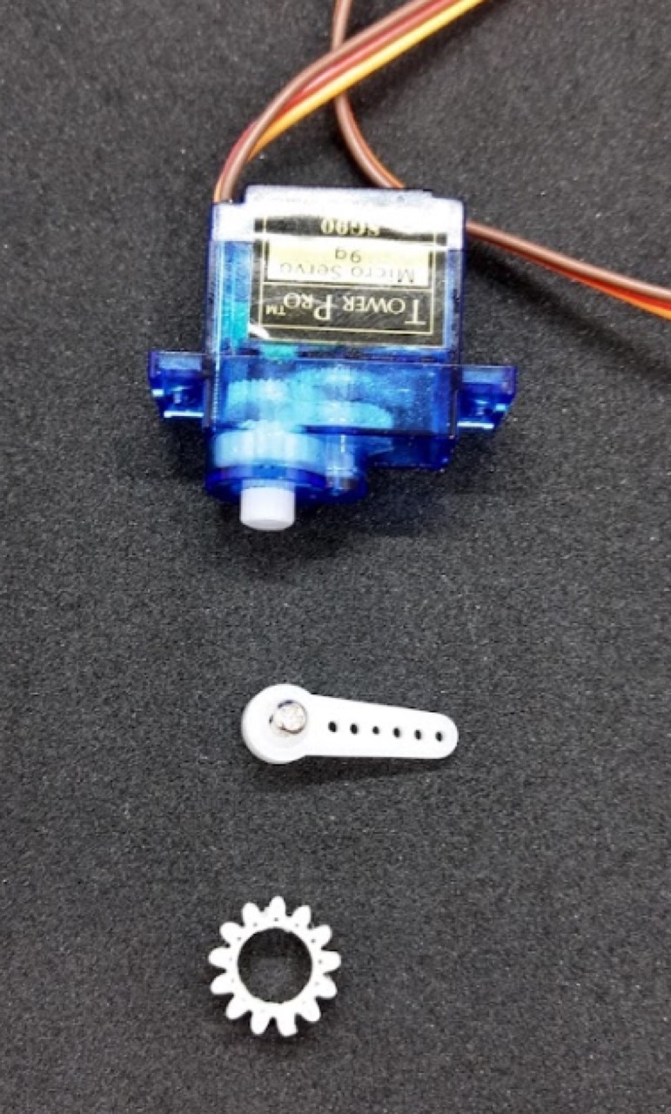
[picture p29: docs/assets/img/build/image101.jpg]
Cutting the horn
  <figure class="figure"><figcaption>Cut the horn to a hub.</figcaption></figure>
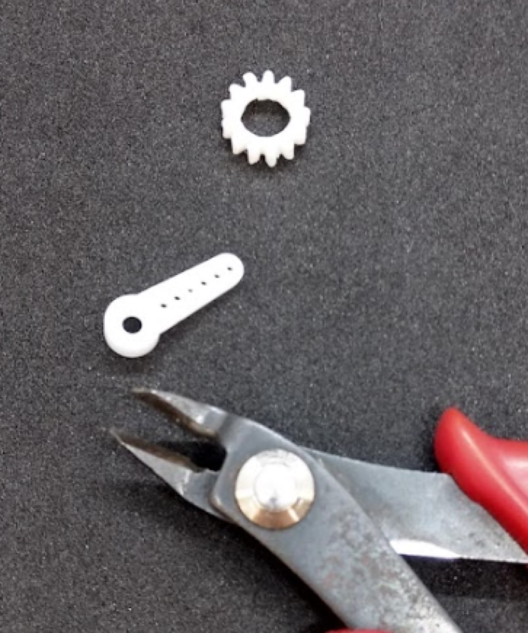
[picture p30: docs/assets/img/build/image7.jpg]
Horn hub
  <figure class="figure"><figcaption>Hub only.</figcaption></figure>
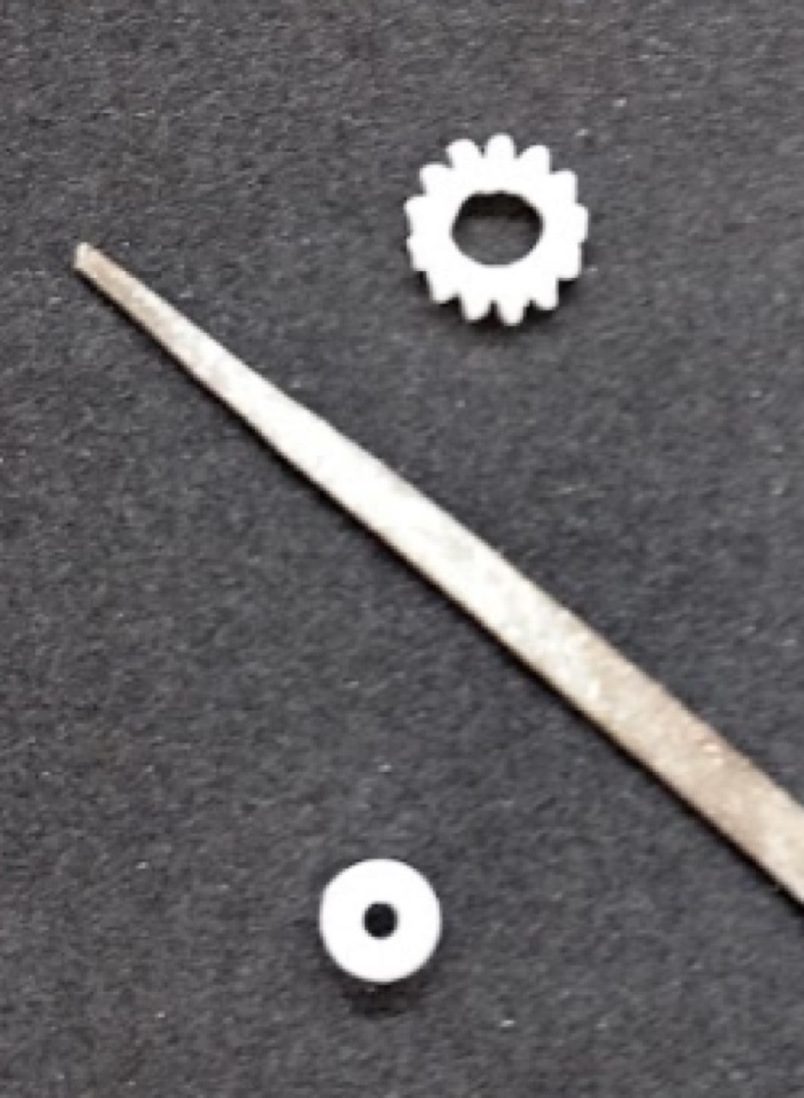
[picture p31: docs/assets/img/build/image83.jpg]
Hub in gear
  <figure class="figure"><figcaption>Press-fit, then glue.</figcaption></figure>
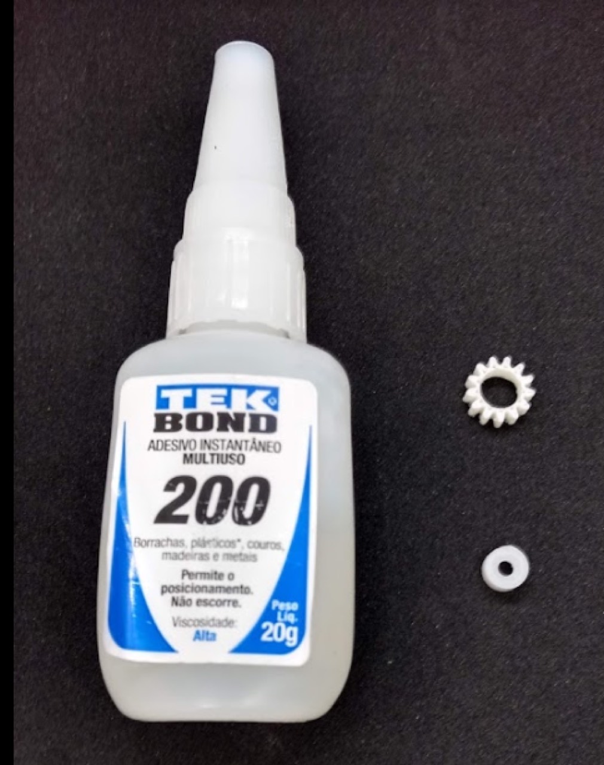
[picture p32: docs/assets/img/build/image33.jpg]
Glued gear
  <figure class="figure"><figcaption>Keep glue off the teeth.</figcaption></figure>
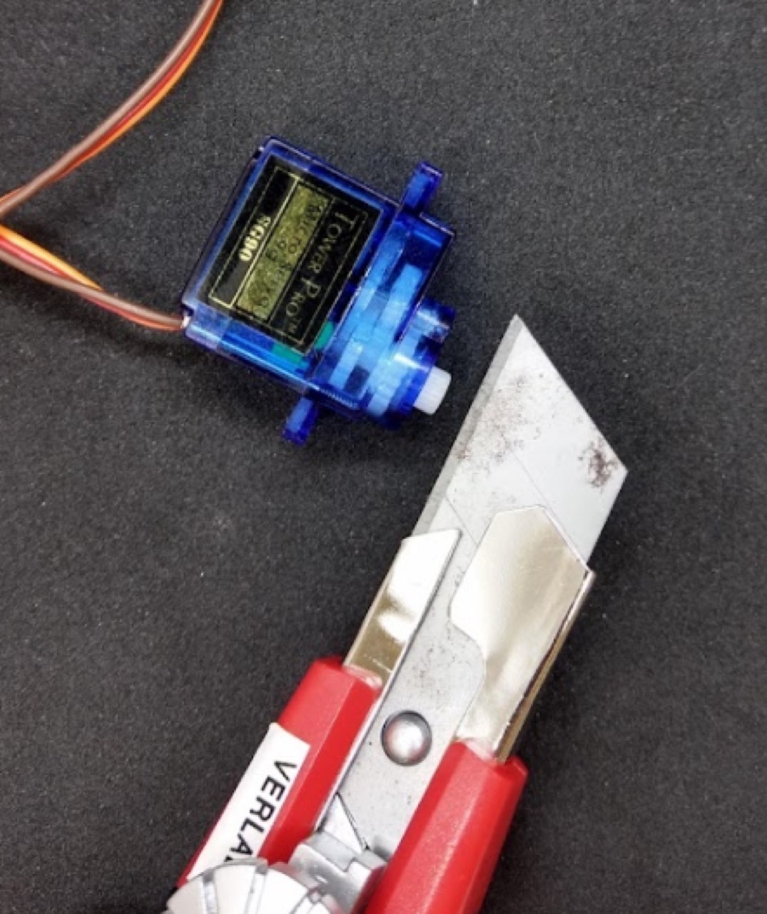
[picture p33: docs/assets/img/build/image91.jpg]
Shortening the shaft
  <figure class="figure"><figcaption>Shorten the shaft if needed.</figcaption></figure>
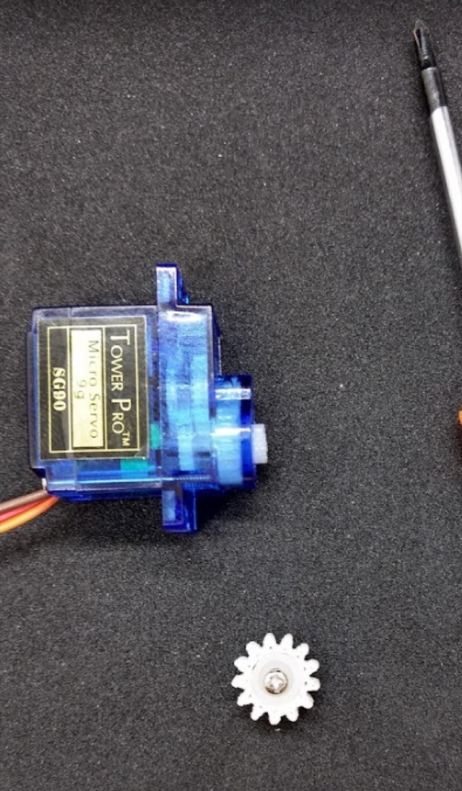
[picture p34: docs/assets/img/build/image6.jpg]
Horn screw
  <figure class="figure"><figcaption>Original horn screw.</figcaption></figure>
</div>

Mount each servo on Chassis A. Align both outputs at the stop pulse (1500 µs). Leave the mount screws slightly loose so the 1:1 gear train can sit. Trim motor cables to about 10 cm.

<div class="figure-grid">
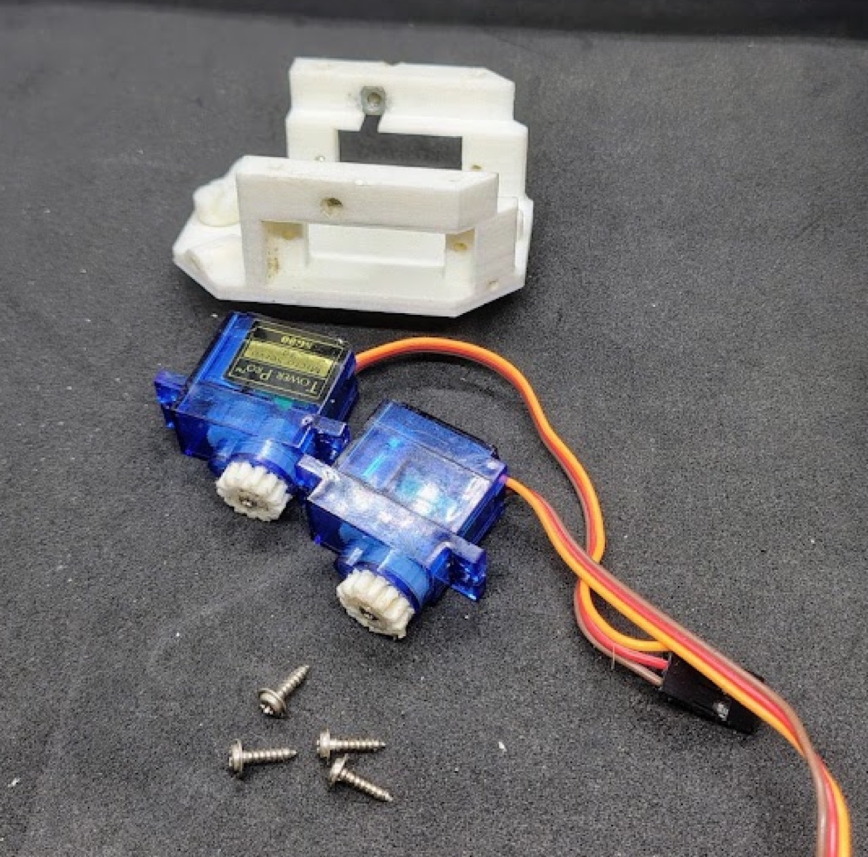
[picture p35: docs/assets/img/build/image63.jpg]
Servo on chassis
  <figure class="figure"><figcaption>Servo in the printed mount.</figcaption></figure>
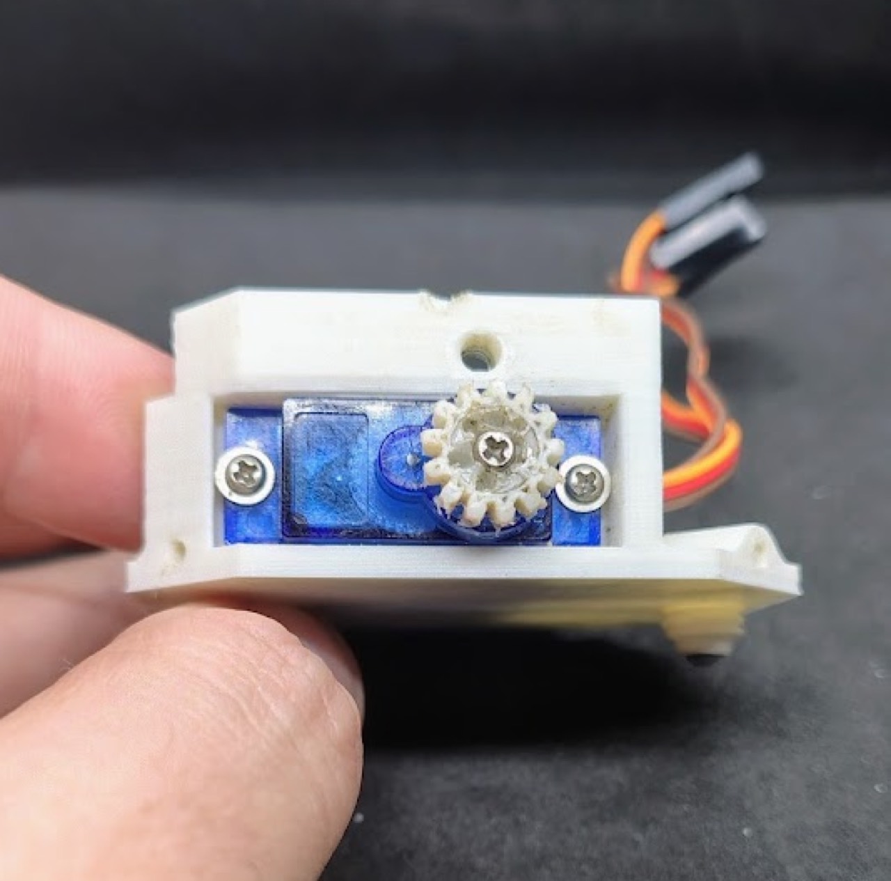
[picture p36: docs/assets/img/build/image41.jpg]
Both motors installed
  <figure class="figure"><figcaption>Both sides aligned.</figcaption></figure>
</div>

The paper’s drivetrain is a **1:1 motor–wheel gear** plus a **1:6 wheel–encoder gear**. Combined with the 48 PPR mouse encoder that is a **1.25° / 0.54 mm** wheel step.

## Wheels {#wheels}

Press a 623ZZ into each printed hub (vise or a flat spacer — do not hammer the bearing). Seat the O-ring. Fit the printed shaft sleeve so the wheel turns with almost no backlash and no wobble.

<div class="figure-grid">
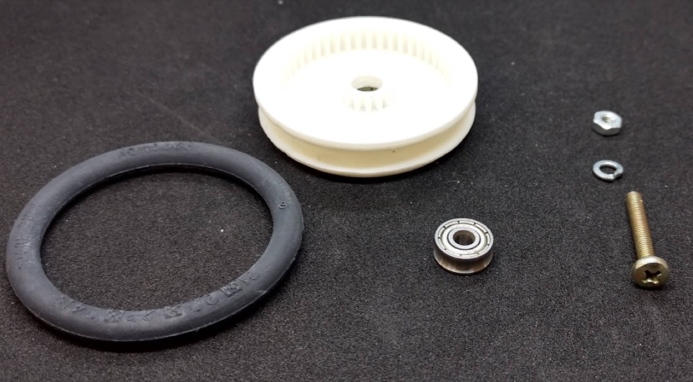
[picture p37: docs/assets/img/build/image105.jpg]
Wheel parts
  <figure class="figure"><figcaption>Wheel kit.</figcaption></figure>
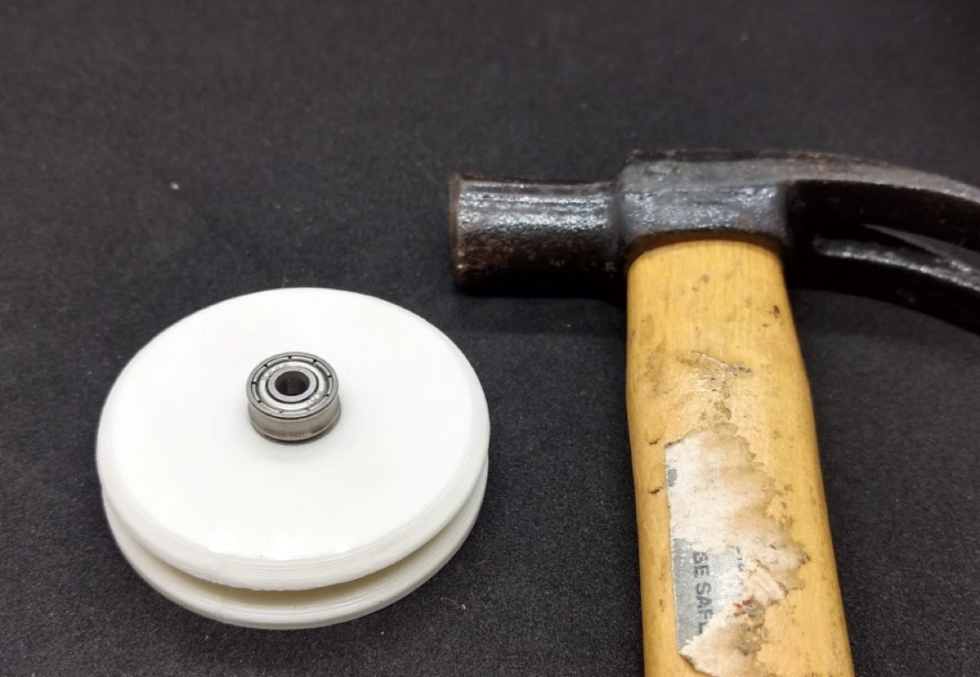
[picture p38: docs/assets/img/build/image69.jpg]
Pressing the bearing
  <figure class="figure"><figcaption>Press the 623ZZ.</figcaption></figure>
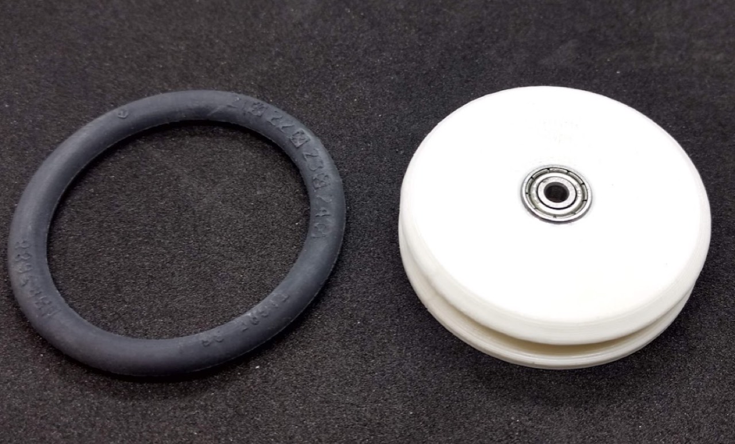
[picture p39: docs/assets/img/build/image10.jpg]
O-ring tire
  <figure class="figure"><figcaption>O-ring on the rim.</figcaption></figure>
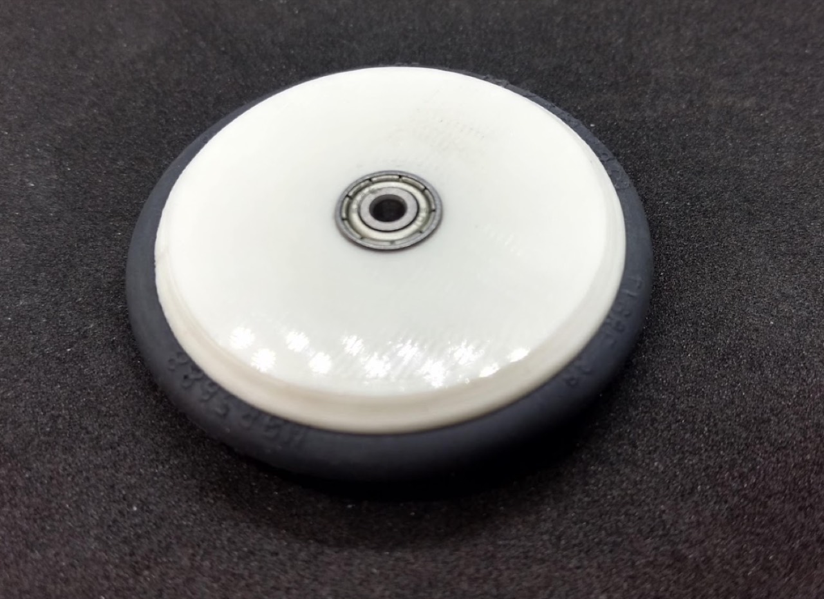
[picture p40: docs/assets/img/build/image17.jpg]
Finished wheel
  <figure class="figure"><figcaption>Ready to mesh.</figcaption></figure>
</div>

Install the wheel on the motor gear. The mesh should be smooth. A tiny drop of glue on the support screw into Chassis A keeps it from backing out.

<div class="figure-grid">
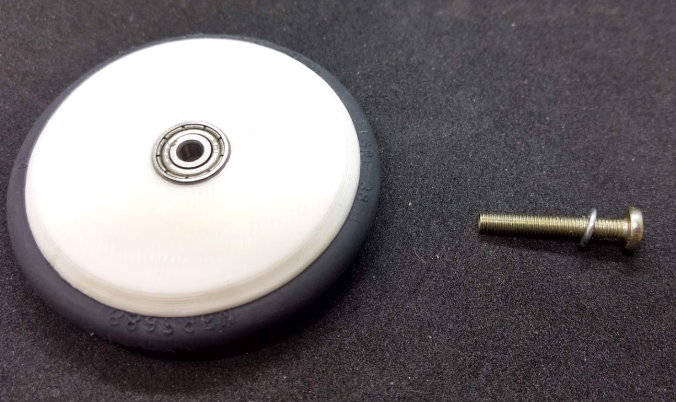
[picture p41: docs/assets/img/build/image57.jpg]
Wheel on shaft
  <figure class="figure"><figcaption>Wheel on the axle.</figcaption></figure>
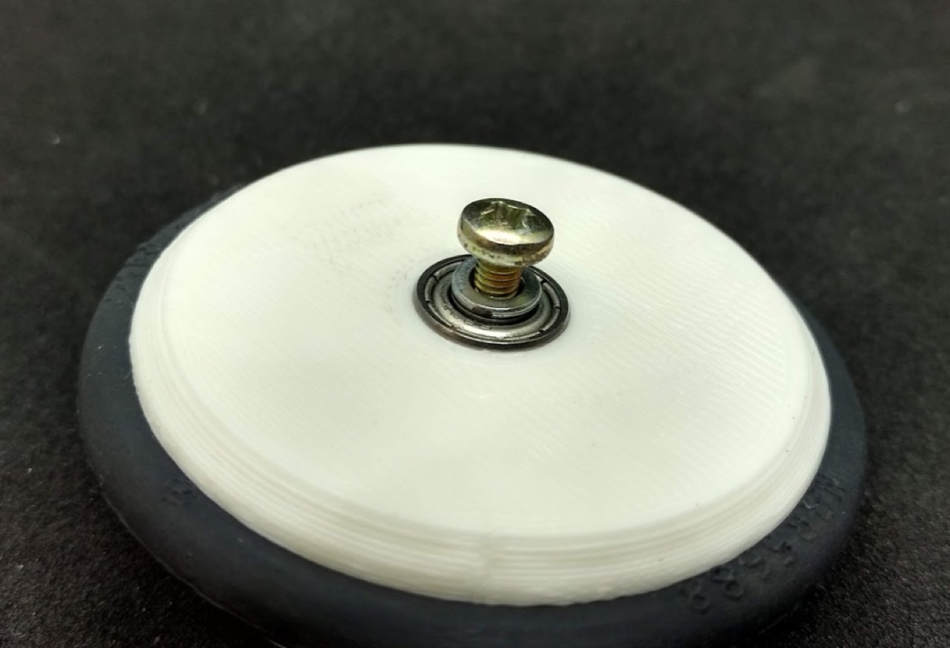
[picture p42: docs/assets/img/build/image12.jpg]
Gear mesh
  <figure class="figure"><figcaption>Motor gear to wheel.</figcaption></figure>
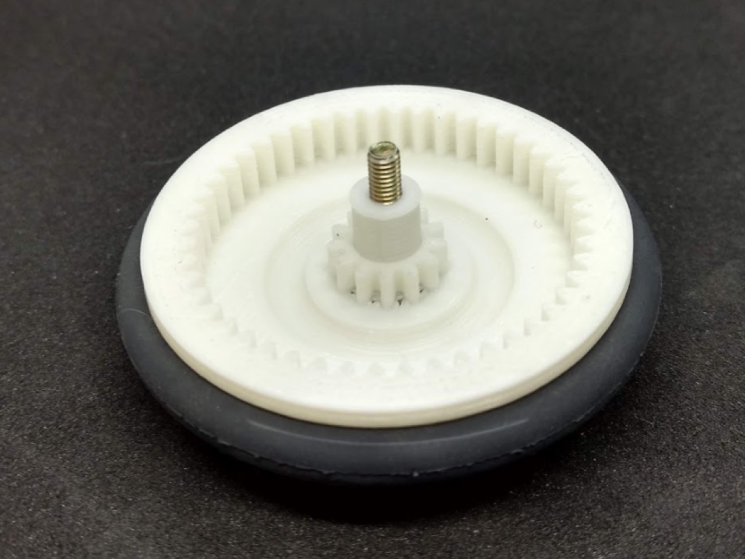
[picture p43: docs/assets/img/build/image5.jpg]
Support screw
  <figure class="figure"><figcaption>Support screw.</figcaption></figure>
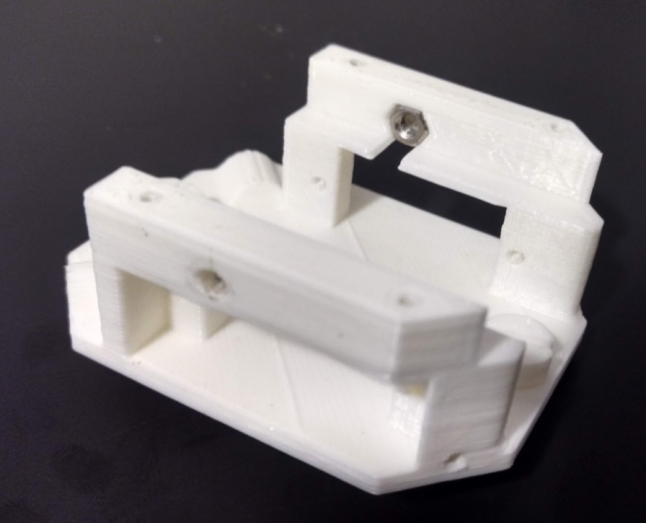
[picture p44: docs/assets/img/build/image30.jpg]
Both wheels
  <figure class="figure"><figcaption>Check for wobble.</figcaption></figure>
</div>

## Battery and Chassis B {#battery}

Seat the 1S Li-Po (paper: 3.7 V, 1800 mAh) in the cradle between A and B. Chassis B is labeled **USB** and **Front**: battery cable through USB, motor cables through Front.

<div class="callout warn">A cover screw that is too long can pierce the pack. Check length before you tighten the top shell.</div>

<div class="figure-grid">
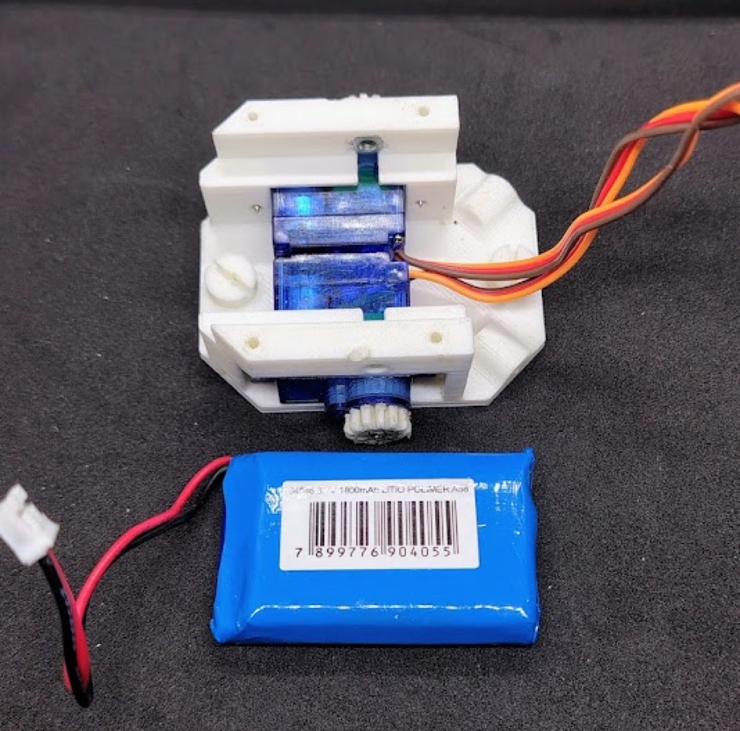
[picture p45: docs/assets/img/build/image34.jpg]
Battery in cradle
  <figure class="figure"><figcaption>Battery in the cradle.</figcaption></figure>
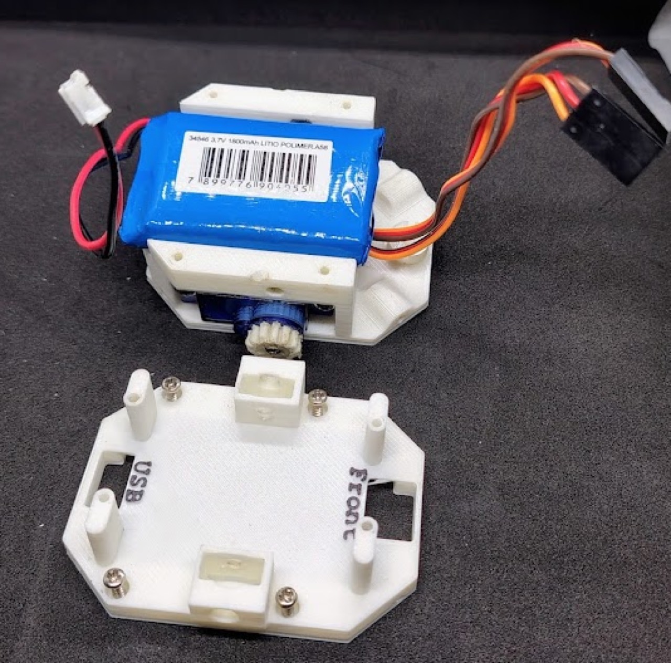
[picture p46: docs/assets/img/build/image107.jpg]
Cable routing
  <figure class="figure"><figcaption>USB vs Front holes.</figcaption></figure>
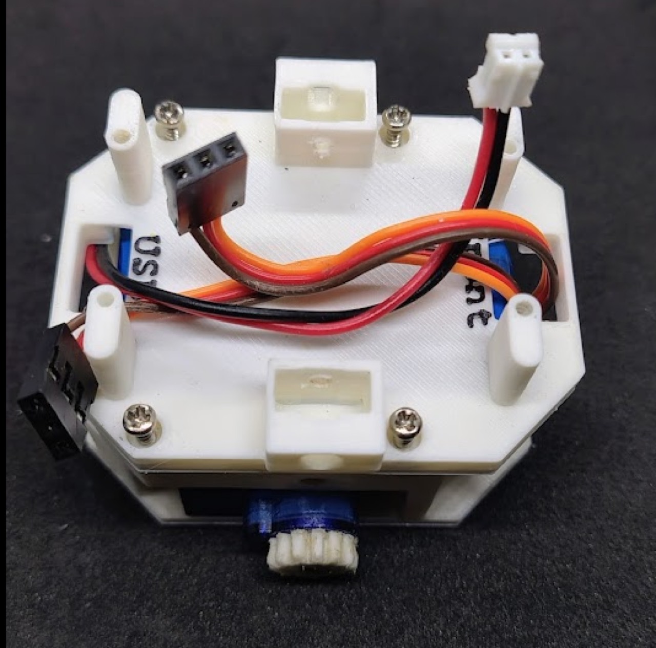
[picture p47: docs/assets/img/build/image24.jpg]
Stacking chassis B
  <figure class="figure"><figcaption>Stack B on A.</figcaption></figure>
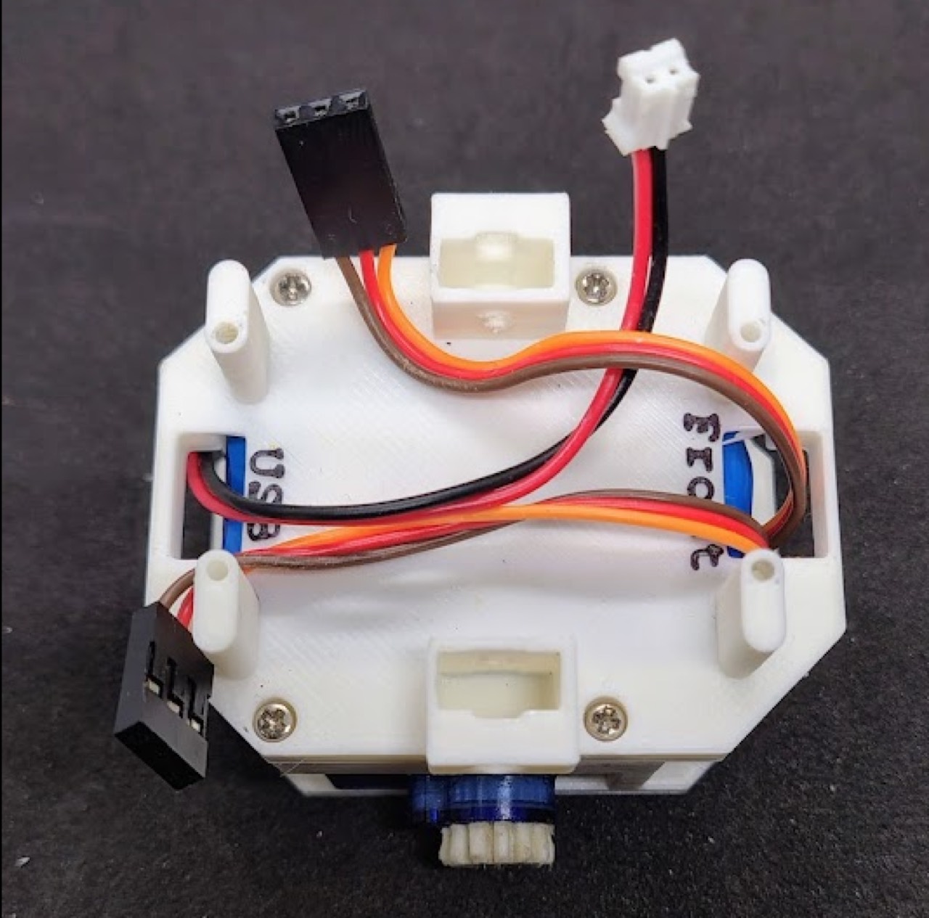
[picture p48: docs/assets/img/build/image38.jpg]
Four screws
  <figure class="figure"><figcaption>Four screws.</figcaption></figure>
</div>

## Encoders {#encoders}

Mouse-style quadrature encoders. Remove the detent spring so the shaft is smooth. Solder a JST-PH header. Cut shafts to length; wear glasses.

<div class="figure-grid">
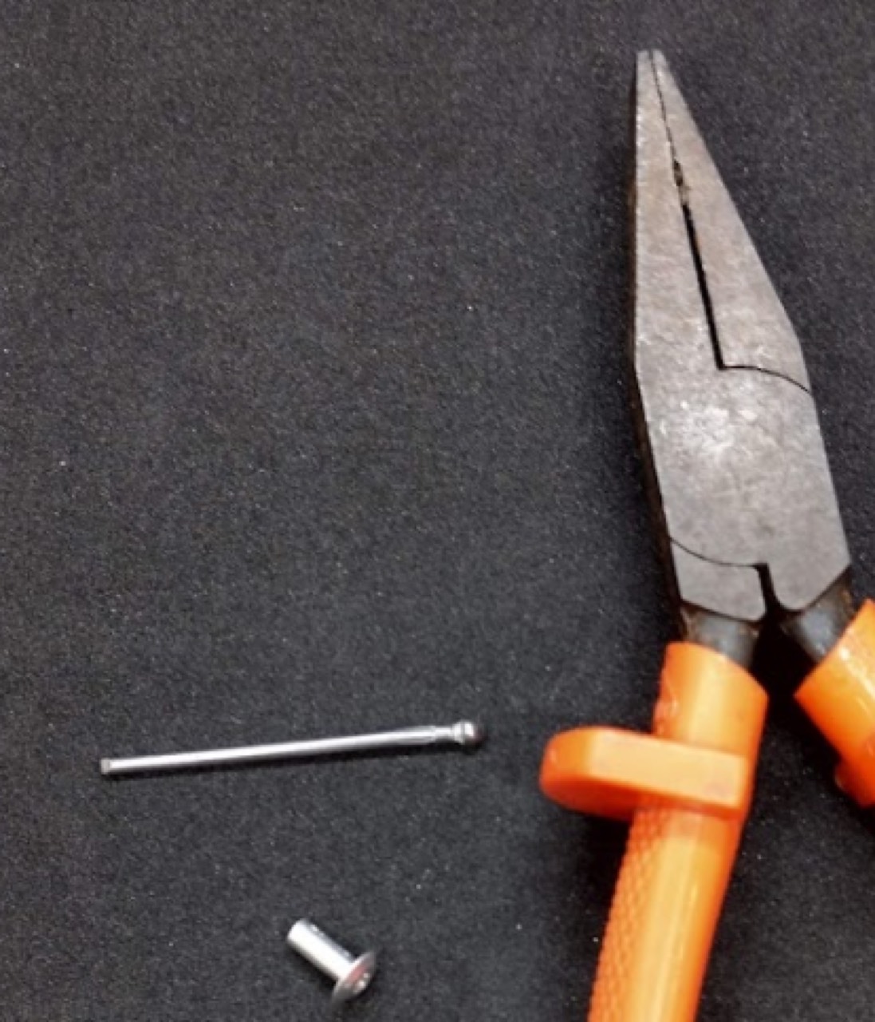
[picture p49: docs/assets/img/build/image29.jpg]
Encoder spring
  <figure class="figure"><figcaption>Drop the detent spring.</figcaption></figure>
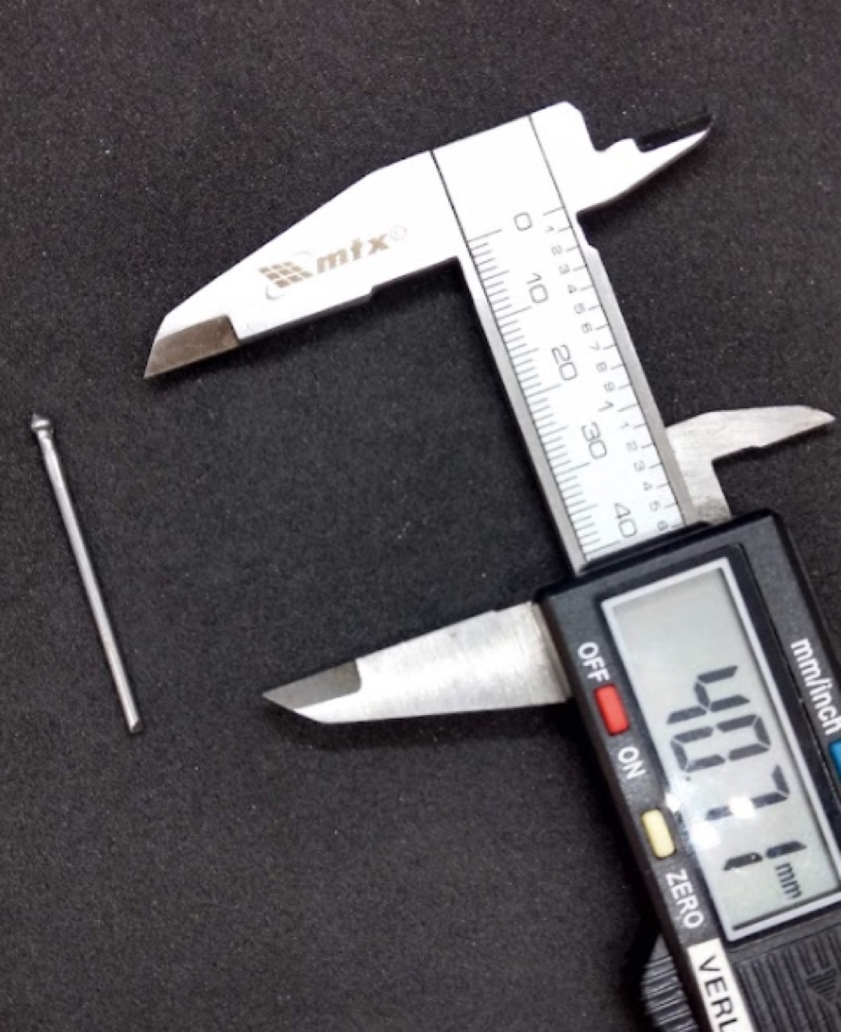
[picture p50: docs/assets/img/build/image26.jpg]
Encoder wiring
  <figure class="figure"><figcaption>JST-PH on the pins.</figcaption></figure>
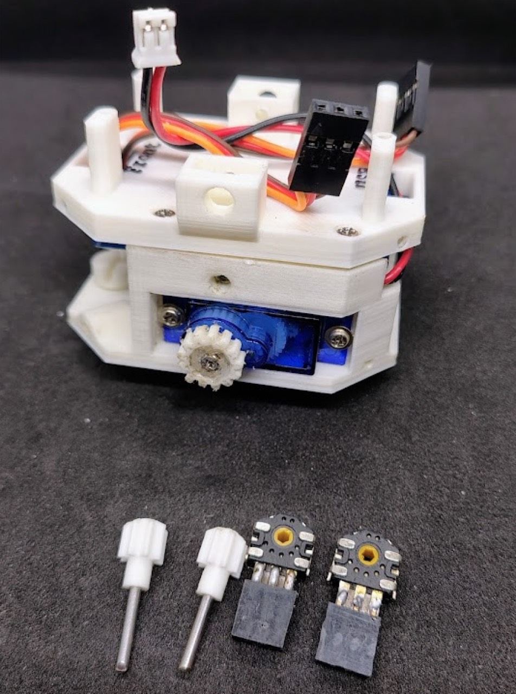
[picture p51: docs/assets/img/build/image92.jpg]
Encoder in chassis B
  <figure class="figure"><figcaption>Pocket in Chassis B.</figcaption></figure>
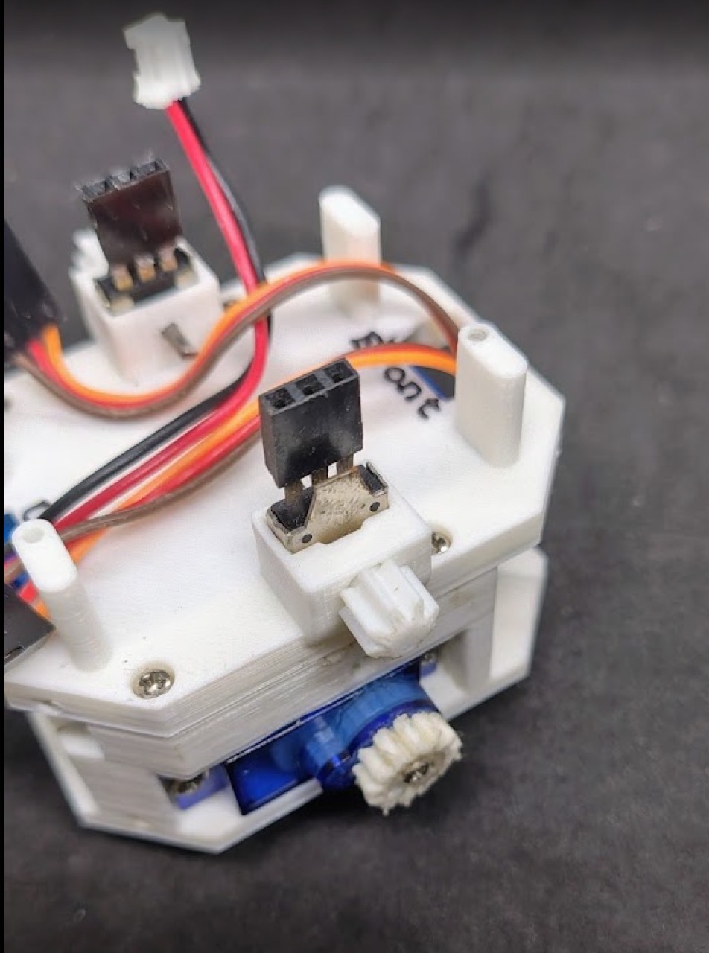
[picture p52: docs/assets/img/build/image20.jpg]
Encoder gear mesh
  <figure class="figure"><figcaption>Gear to the wheel. Sand if it binds.</figcaption></figure>
</div>

## Board, cover, wiring {#board}

Mount the populated PCB on Chassis B. Fit the cover with eight screws — moderate torque. Then put the wheels on for the final motor → wheel → encoder check.

<div class="figure-grid">
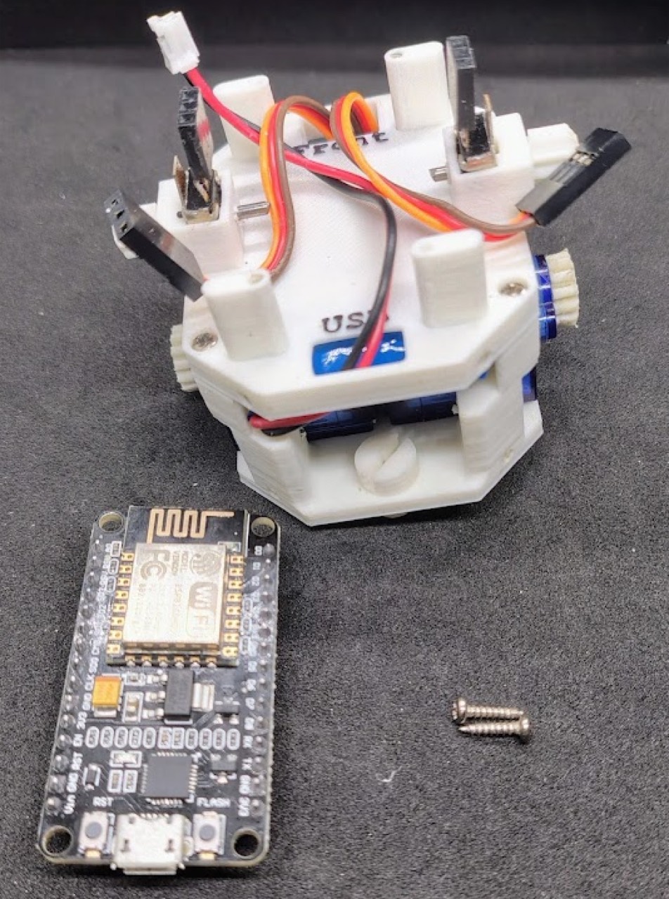
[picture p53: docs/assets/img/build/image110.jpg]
Board on chassis B
  <figure class="figure"><figcaption>Board on B.</figcaption></figure>
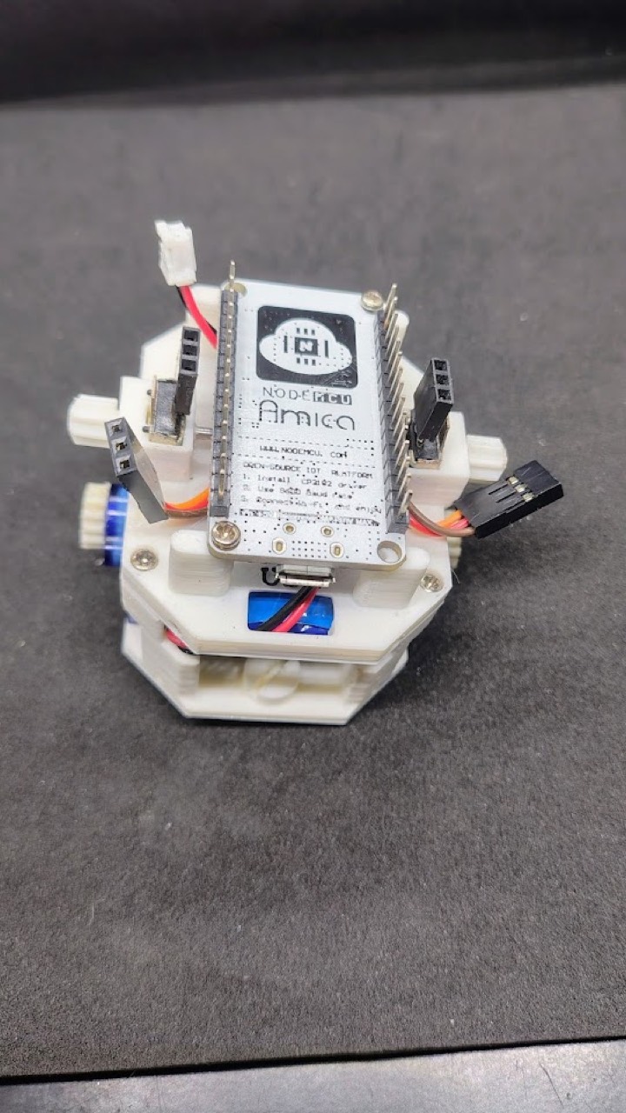
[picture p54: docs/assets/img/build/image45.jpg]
ESP seated
  <figure class="figure"><figcaption>ESP / NodeMCU seated.</figcaption></figure>
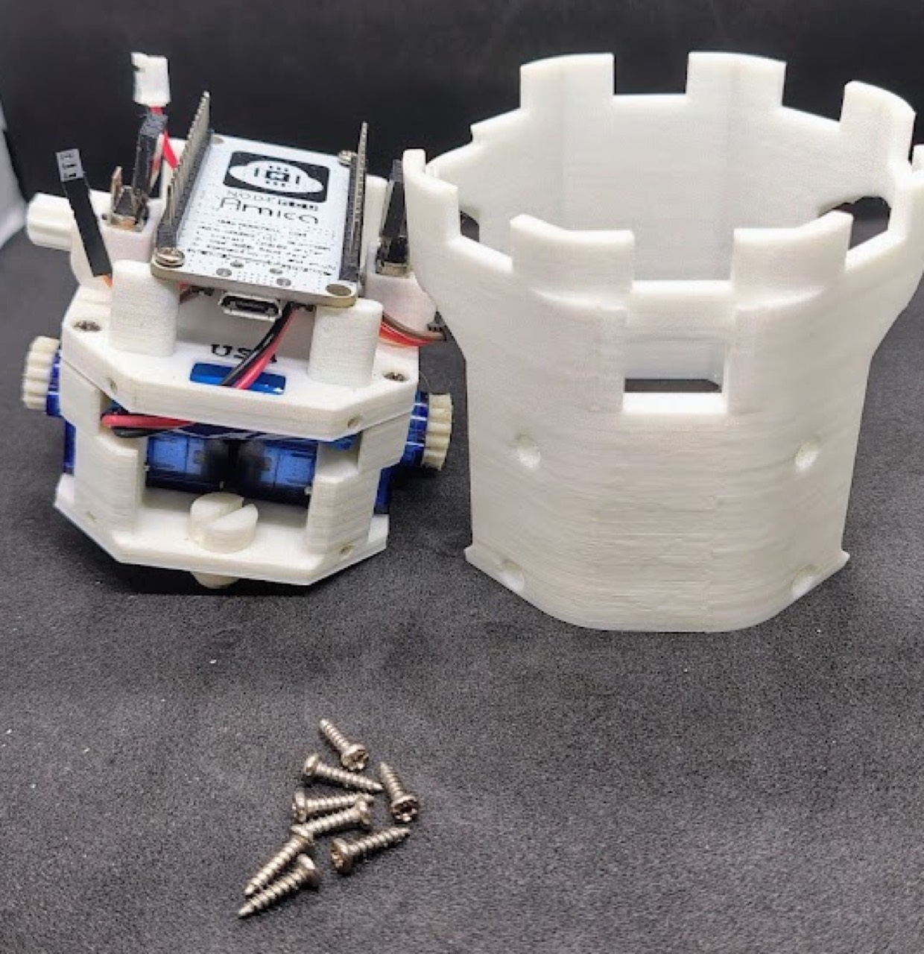
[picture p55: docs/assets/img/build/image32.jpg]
Cover
  <figure class="figure"><figcaption>Cover.</figcaption></figure>
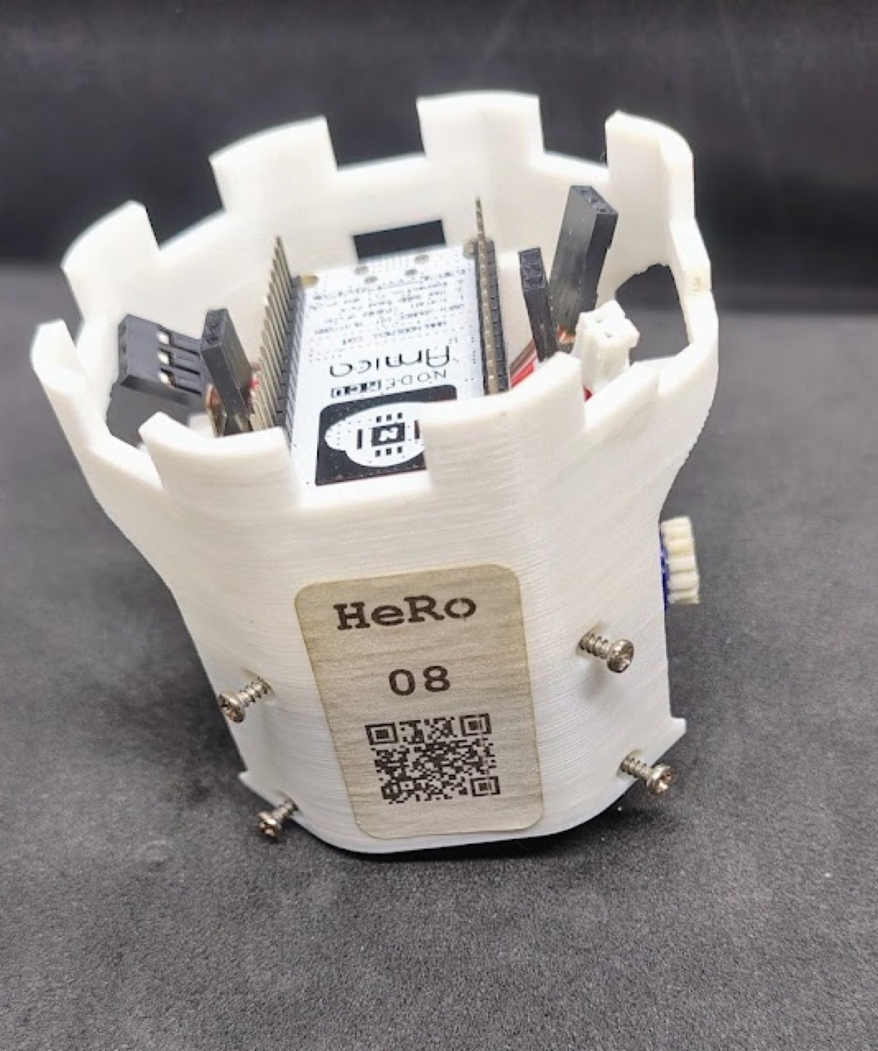
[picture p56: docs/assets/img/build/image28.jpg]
Cover screws
  <figure class="figure"><figcaption>Eight screws, clear of the pack.</figcaption></figure>
</div>

Servo leads: signal to PWM, red to 5 V, brown/black to GND. Battery JST last. Never reverse the pack.

<div class="figure-grid">
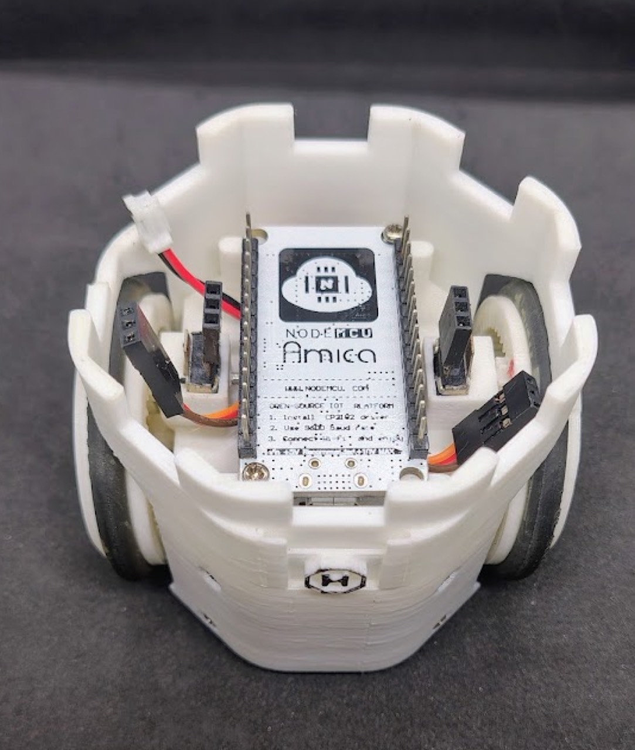
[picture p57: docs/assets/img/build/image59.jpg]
Servo plugs
  <figure class="figure"><figcaption>Servo plugs.</figcaption></figure>
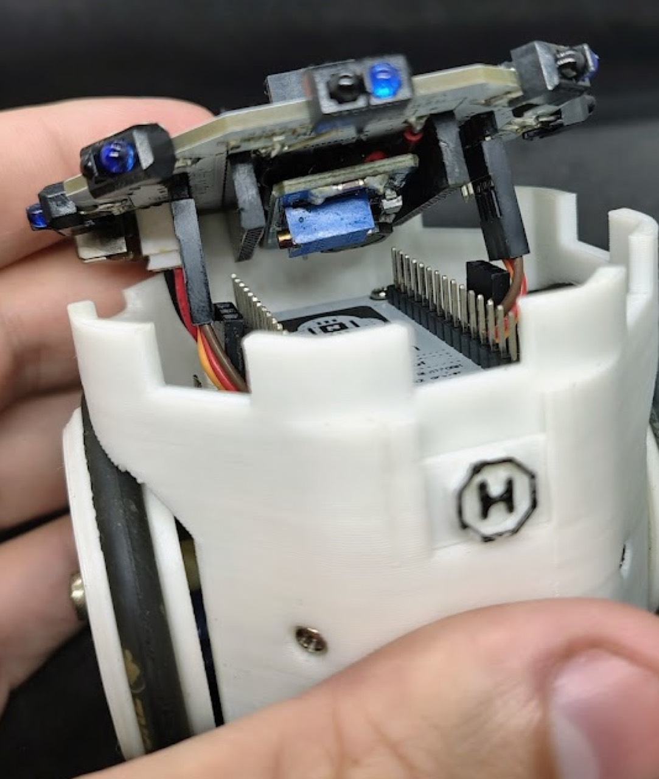
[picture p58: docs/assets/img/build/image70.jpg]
Battery JST
  <figure class="figure"><figcaption>Battery JST.</figcaption></figure>
</div>

## E-hat {#ehat}

The paper’s e-hat is a 4-pin I²C/UART bus with 5 V at 800 mA. Solder male headers on the MPU6050, screw it into the printed hat, and plug the hat onto the I²C connector.

<div class="figure-grid">
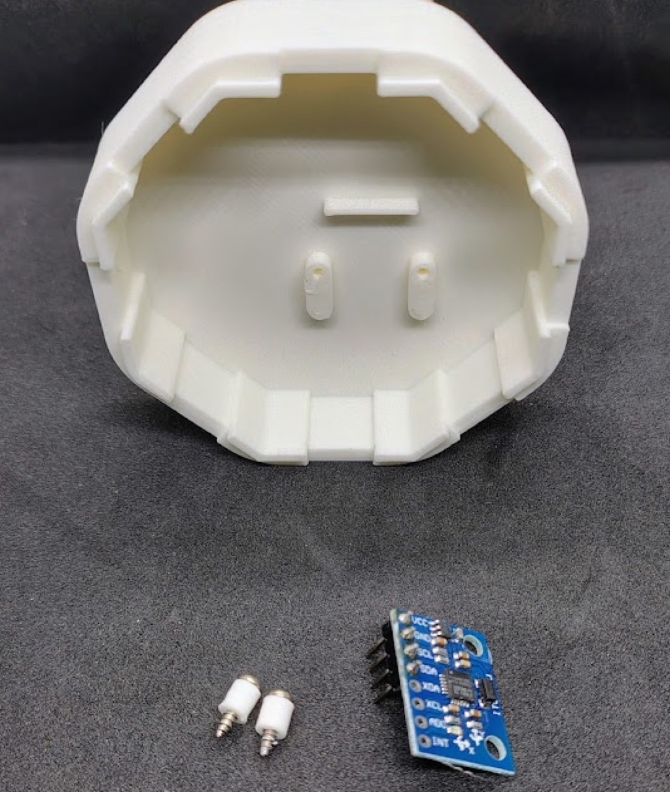
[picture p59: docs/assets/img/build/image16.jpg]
IMU headers
  <figure class="figure"><figcaption>IMU headers.</figcaption></figure>
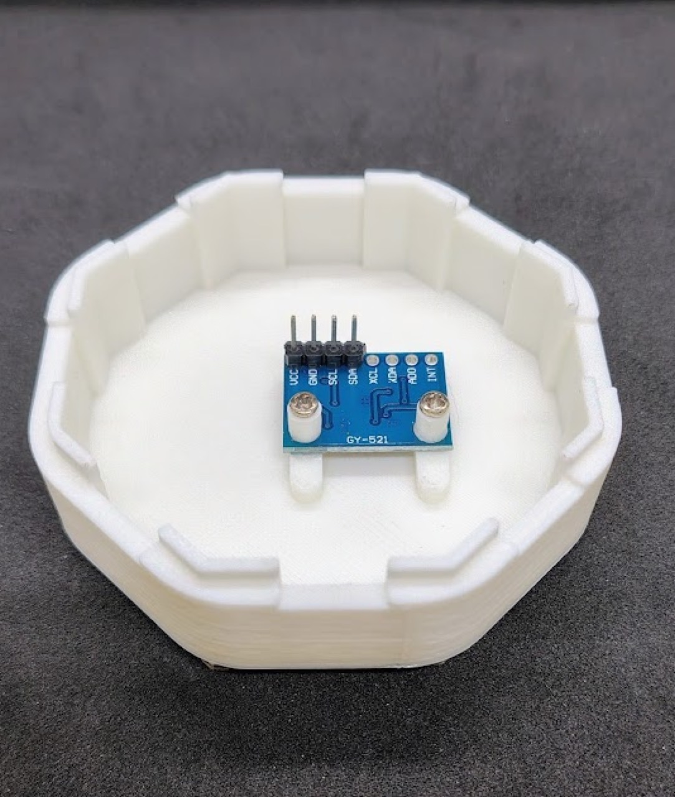
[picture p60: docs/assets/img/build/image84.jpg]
IMU in e-hat
  <figure class="figure"><figcaption>IMU in the hat.</figcaption></figure>
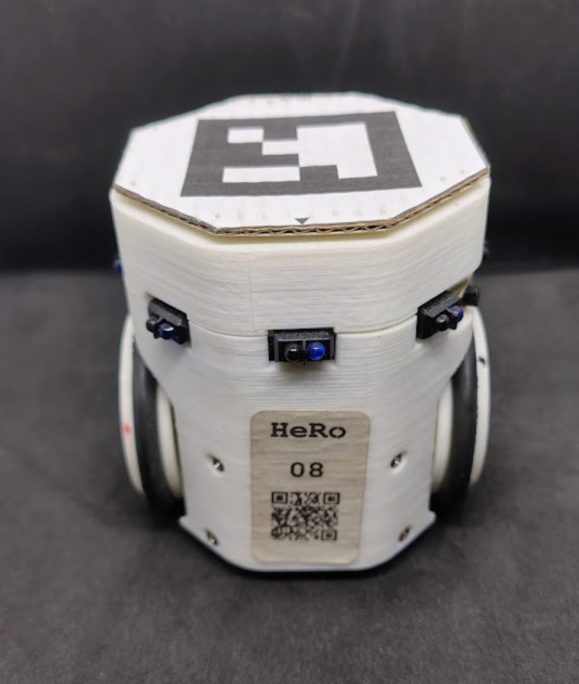
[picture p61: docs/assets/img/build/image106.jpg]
E-hat on the robot
  <figure class="figure"><figcaption>Hat on the I²C bus.</figcaption></figure>
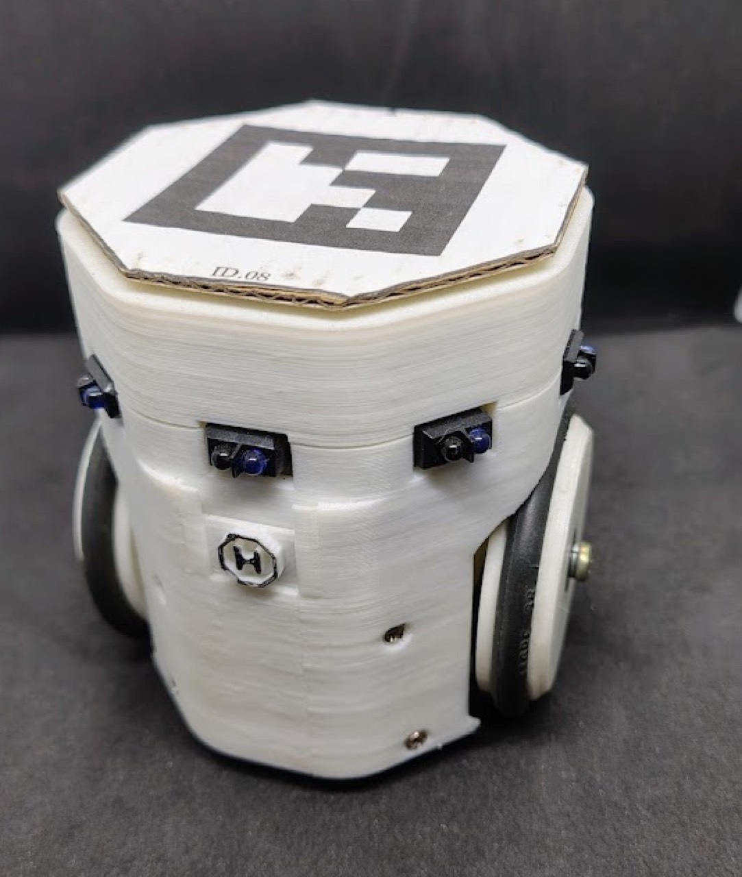
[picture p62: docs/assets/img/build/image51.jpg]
Finished robot
  <figure class="figure"><figcaption>Mechanical check: free wheels, casters, no cable rub.</figcaption></figure>
</div>

## Troubleshooting {#trouble}

| Symptom | What the tutorial says to check |
|---|---|
| Motors dead or weak | PWM–5 V–GND order; boost still 5 V under load; pack &gt; 3.6 V |
| Wheel wobble / backlash | Hub seating, bearings fully in, sand or shim the gear adapter |
| Encoder drops counts | Detent fully gone, JST joints, no lateral shaft play |
| IR silent | Sensor orientation, LED polarity, current-limit resistors |
| Board off | MT3608 at 5.0 V, JST polarity, switch solder |
| Boost hot | Stay ≤ 0.8 A continuous or add a heatsink |

Next: [flash firmware]({{ '/firmware/' | relative_url }}), [join ROS]({{ '/ros/' | relative_url }}), then [calibrate]({{ '/calibration/' | relative_url }}).

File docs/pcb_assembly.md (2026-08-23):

---
layout: page
title: Solder the board
permalink: /pcb_assembly/
section: build
lead: SMD first, then through-hole. The tutorial times this at about 20 minutes of reading and 130 minutes of building. Figures are from the HeRo V2 Robot Build Tutorial (v1.0, 27 Sep 2025).
---

<p class="toc"><a href="#passives">Passives</a> · <a href="#ics">ICs</a> · <a href="#leds">LEDs</a> · <a href="#connectors">Connectors</a> · <a href="#ir">IR sensors</a> · <a href="#boost">5 V boost</a> · <a href="#checks">Checks</a></p>

Work current-limited (≤300 mA) until the smoke test. Treat the Li-Po as a live cell once it is connected.

<div class="figure-grid">
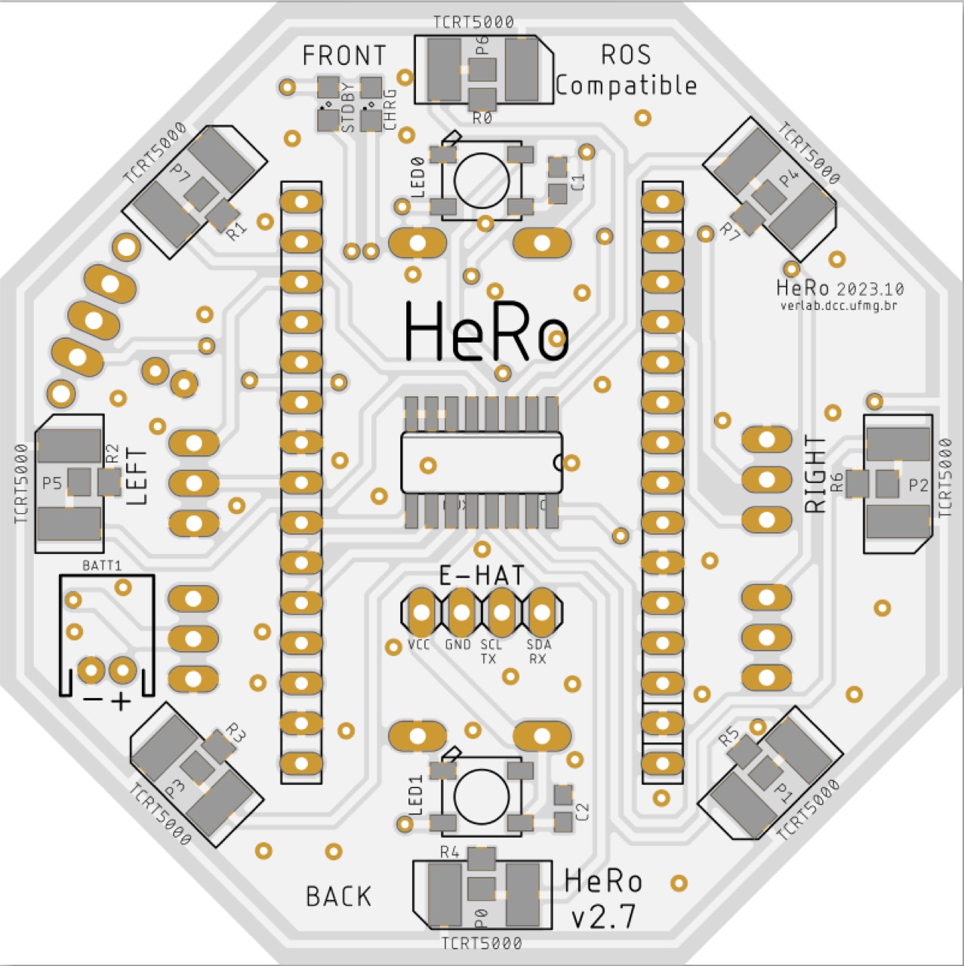
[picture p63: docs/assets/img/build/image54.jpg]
Tools for PCB work
  <figure class="figure"><figcaption>Bench tools.</figcaption></figure>
  <figure class="figure">Populated HeRo board<figcaption>A finished board.</figcaption></figure>
</div>

## BOM on the board

- Passives: R0–R8 (4k7), R9 (0 Ω), R10 (18 Ω), R15 (0 Ω), C1–C2 (100 pF). R11 is not mounted.
- Indicators: LED0–LED1 (WS2812B 5050). Optional charger LEDs: STDBY green 0805, CHRG red 0805.
- ICs: IRLML2502 (SOT-23), CD4051 (SOIC-16), TP4056 (SOP-8, optional charger).
- Sensors: TCRT5000L ×8.
- Connectors: two JST-PH-2, 1×4 female (I²C/UART), four 1×3 male (E/M), two 1×16 female (ESP), slide switch.

<figure class="figure">
  Blank HeRo PCB
  <figcaption>Blank HeRo v2 board. Order Gerbers from the previous step if you do not have one.</figcaption>
</figure>

## Soldering order (SMD → THT)

<p class="step-meta" id="passives">About 90 minutes on the iron</p>

**1. Small passives** — C0603 then R0805 (C1–C2; C3–C4 optional; R0–R10, R12–R15). Leave R11 empty.

<div class="figure-grid">
  <figure class="figure">SMD capacitors<figcaption>Capacitors.</figcaption></figure>
  <figure class="figure">SMD resistors<figcaption>Resistors.</figcaption></figure>
</div>

**2. ICs** — TP4056 if you want onboard charge, then CD4051, then IRLML2502. Pin-1 / orientation dot to the silkscreen. Inspect bridges.

<div class="figure-grid" id="ics">
  <figure class="figure">IC soldering<figcaption>ICs on the board.</figcaption></figure>
  <figure class="figure">IC orientation<figcaption>Match the pin-1 mark.</figcaption></figure>
</div>

**3. Addressable LEDs** — WS2812B, arrow DIN → DOUT, polarity to silk. Continuity-check the pads.

<div class="figure-grid" id="leds">
  <figure class="figure">WS2812B LEDs<figcaption>WS2812B orientation.</figcaption></figure>
  <figure class="figure">Status LEDs<figcaption>Optional STDBY / CHRG LEDs.</figcaption></figure>
</div>

**4. Connectors and switch** — JST-PH-2 ×2, I²C/UART header, encoder/motor headers, ESP sockets, slide switch.

<div class="figure-grid" id="connectors">
  <figure class="figure">Headers<figcaption>Headers.</figcaption></figure>
  <figure class="figure">Switch and sockets<figcaption>Switch and ESP sockets.</figcaption></figure>
</div>

**5. IR sensors** — eight TCRT5000L, same standoff, coplanar, gap aligned around the ring.

<div class="figure-grid" id="ir">
  <figure class="figure">TCRT5000 sensors<figcaption>TCRT5000 ring.</figcaption></figure>
  <figure class="figure">IR alignment<figcaption>Keep them coplanar.</figcaption></figure>
</div>

## Tune the MT3608 to 5.0 V {#boost}

The paper uses an MT3608 step-up so the 3.7 V pack becomes a 5 V rail (motors included).

1. PSU + → VIN+, PSU GND → VIN−. Meter on VOUT+/VOUT−.
2. Set the bench supply to 4.0 V, current limit 0.30 A.
3. Turn the trimpot slowly toward 5.00 V. Do not overshoot.
4. Recheck under a short dummy load: 100 Ω (~50 mA), then 6.2 Ω (~0.8 A) or 5 Ω (~1.0 A) in bursts.
5. Power off. Mark the module “5 V”.

<div class="figure-grid">
  <figure class="figure">MT3608 wiring<figcaption>Boost module on the bench.</figcaption></figure>
  <figure class="figure">Measuring 5 V<figcaption>Trim to 5.00 V.</figcaption></figure>
</div>

## Electrical checks {#checks}

Unpowered: GND continuity; 0 Ω jumpers R9/R15; no 5 V↔GND or 3V3↔GND shorts.

Powered (bench or battery): 5.0 V / 0.3 A limit, switch on, watch quiescent current. Nothing should run hot.

<div class="figure-grid">
  <figure class="figure">Power-up check<figcaption>First power-up.</figcaption></figure>
  <figure class="figure">Current-limited supply<figcaption>Stay current-limited.</figcaption></figure>
</div>

Drive the WS2812B with a blink or rainbow. Confirm I²C pull-ups (~4.7 kΩ to 3V3) and an MPU6050 ACK if the e-hat is fitted. Walk the CD4051 channels; IR voltages should move with a white/black card.

<div class="figure-grid">
  <figure class="figure">LED test<figcaption>LED bring-up.</figcaption></figure>
  <figure class="figure">IR channel test<figcaption>IR / mux check.</figcaption></figure>
</div>

Optional smoke test: flash the stock firmware over USB (battery disconnected) and watch the serial boot at 115200.

<p><a class="btn btn-primary" href="{{ '/printing/' | relative_url }}">Next: print the body</a></p>

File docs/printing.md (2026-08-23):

---
layout: page
title: Print the body
permalink: /printing/
section: build
lead: PLA, 0.20 mm layers, 0.4 mm nozzle. Gears print cleaner with a finer nozzle. CAD on A360.
---

<div class="part-grid">
  <article class="part-card">
    
    <h3>Chassis A</h3>
    <p>Motors and wheel shafts · 20% infill · support</p>
    <a href="{{ '/assets/models/chassis_a.stl' | relative_url }}" download>Download chassis_a.stl</a>
  </article>
  <article class="part-card">
    
    <h3>Chassis B</h3>
    <p>Board, encoders, battery · 20% infill · no support</p>
    <a href="{{ '/assets/models/chasis_b.stl' | relative_url }}" download>Download chasis_b.stl</a>
  </article>
  <article class="part-card">
    
    <h3>Wheel ×2</h3>
    <p>623ZZ press-fit · 20% infill · support</p>
    <a href="{{ '/assets/models/wheel.stl' | relative_url }}" download>Download wheel.stl</a>
  </article>
  <article class="part-card">
    
    <h3>Castor ×2</h3>
    <p>4 mm ball · 100% infill · no support</p>
    <a href="{{ '/assets/models/castor_wheel.stl' | relative_url }}" download>Download castor_wheel.stl</a>
  </article>
  <article class="part-card">
    
    <h3>Motor gear ×2</h3>
    <p>1:1 to the wheel · 100% infill · no support</p>
    <a href="{{ '/assets/models/motor_gear.stl' | relative_url }}" download>Download motor_gear.stl</a>
  </article>
  <article class="part-card">
    
    <h3>Motor shaft ×2</h3>
    <p>Wheel axle sleeve · 100% infill · no support</p>
    <a href="{{ '/assets/models/motor_shaft.stl' | relative_url }}" download>Download motor_shaft.stl</a>
  </article>
  <article class="part-card">
    
    <h3>Encoder shaft ×2</h3>
    <p>1:6 to the wheel · 100% infill · no support</p>
    <a href="{{ '/assets/models/encoder_shaft.stl' | relative_url }}" download>Download encoder_shaft.stl</a>
  </article>
  <article class="part-card">
    
    <h3>Cover</h3>
    <p>20% infill · support</p>
    <a href="{{ '/assets/models/cover.stl' | relative_url }}" download>Download cover.stl</a>
  </article>
  <article class="part-card">
    
    <h3>USB slider</h3>
    <p>Door for the USB port</p>
    <a href="{{ '/assets/models/cover_usb.stl' | relative_url }}" download>Download cover_usb.stl</a>
  </article>
  <article class="part-card">
    
    <h3>E-hat</h3>
    <p>20% infill · no support</p>
    <a href="{{ '/assets/models/ehat.stl' | relative_url }}" download>Download ehat.stl</a>
  </article>
  <article class="part-card">
    
    <h3>E-hat glove</h3>
    <p>100% infill · no support</p>
    <a href="{{ '/assets/models/ehat_glove.stl' | relative_url }}" download>Download ehat_glove.stl</a>
  </article>
</div>

## Print settings

| | |
|---|---|
| Printer in the notes | Anet A8 |
| Nozzle | 0.4 mm |
| Filament | PLA |
| Slicer | Cura 4.8 |
| Default layer height | 0.20 mm |

Print the encoder-height shim at 0.10 mm, in 0.1–0.4 mm thicknesses, and keep the one that meshes cleanly.

[Fusion / A360](https://a360.co/3lWHiv0) · [all STLs on GitHub](https://github.com/verlab/hero_common/tree/master/hero_resources/3d_parts)

<p><a class="btn btn-primary" href="{{ '/assembly/' | relative_url }}">Next: assemble the robot</a></p>

<script type="module" src="{{ '/assets/js/stl-viewer.js' | relative_url }}"></script>

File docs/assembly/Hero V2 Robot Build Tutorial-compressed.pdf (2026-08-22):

# HeRo V2 Robot Build Tutorial

Version: 1.0
September 27, 2025
By: Paulo Rezeck, Ph.D

🔗 Official HeRo page (https://verlab.github.io/hero_common/) · 👤 Paulo Rezeck (https://rezeck.github.io/)

This work is licensed under a Creative Commons Attribution-NonCommercial-ShareAlike 4.0 International License. (http://creativecommons.org/licenses/by-nc-sa/4.0/)

# Introduction

Welcome, future robot builders! Get ready to embark on an exciting journey to construct your very own HeRo V2 robot. This tutorial will guide you step-by-step through the assembly process, from unboxing to your fi rst successful boot-up. Let's get building!


## What You'll Need

HeRo V2 Robot Parts
Phillips and fl at-head screwdrivers (small/medium) Pliers: needle‑nose, diagonal cutters
Wire cutters/strippers
Precision knife / box cutter
Soldering iron (fi ne tip), solder, fl ux Desoldering pump or braid
Multimeter (continuity/diode) ESD-safe tweezers & mat
Safety glasses
Bench PSU with current limit (optional) Hot air rework station (optional) Isopropyl alcohol & brush
Helping hands / PCB vise

## Structure

Introduction | 2
What You'll Need | 2
Structure | 3
Part I — PCB Board | 4
A. Overview & Required Tools | 4
B. Bill of Materials (BOM) — PCB subset | 4
C. Soldering Order (SMD → THT) | 6
D. Post‑Assembly Electrical Checks | 11
E. Firmware bring‑up (smoke test) | 12
Part II — Robot Assembly | 12
A. Printed/Off‑the‑Shelf Parts | 13
B. Main Assembly Sequence | 14
C. Troubleshooting | 21
Part III — Software Setup & Programming | 22
A. Installation (Docker or source) | 22
B. Firmware (Arduino/ESP8266) | 24
C. ROS Networking & Bring‑up | 28
D. Robot Simulation (Gazebo) | 32
Part IV — Calibration | 35
A. Enter Confi guration Mode | 35
B. Motor PWM Calibration | 36
C. Position Controller PID | 36
D. Velocity Controller PID | 36
E. IR Distance Sensor Calibration | 36

# Part I — PCB Board

Reading time: 20 min
Building time: 130 min

## A. Overview & Required Tools

Reading time: 2 min
Building time: 0 min

Goal: Assemble the HeRo v2 main PCB, verify power, I²C/UART, LEDs, IR sensors, motor/encoder headers, and charging (optional).

Tools: fi ne‑tip soldering iron, hot air (optional), fl ux pen, tweezers, magnifi er, side cutters, multimeter (continuity & diode), bench PSU (current‑limited), USB‑TTL (if needed), ESD mat.

Safety: work current‑limited (≤300 mA until smoke test), Li‑ion handling precautions.


## B. Bill of Materials (BOM) — PCB subset

Reading time: 3 min
Building time: 0 min

Comprehensive BOM: Materials (HeRo v2) (https://verlab.github.io/hero_common/materials/)

(We’ll keep the comprehensive BOM separate; below is a condensed checklist to drive assembly.)

- Passives: R0–R8 (4k7), R9 (0Ω), R10 (18Ω), R15 (0Ω), C1–C2 (100 pF), R11 NM.
- Indicators: LED0–LED1 (WS2812B 5050), STDBY (optional - green 0805), CHRG (optional - red 0805).
- ICs/Modules: IRLML2502 (SOT‑23), CD4051 (SOIC‑16), TP4056 (SOP‑8, optional charger section).
- Sensors/Headers: TCRT5000L ×8, JST‑PH‑2 ×2 (BATT0/1), 1×4 female (I²C|UART), 1×3 male ×4 (E/M LEFT/RIGHT), slide switch SS12F23.
- MCU/Power (modules): ESP‑12E / NodeMCU‑ESP8266 (CP2102), MT3608 boost, MPU6050/GY‑521 IMU, TP4056 charging module (optional-if using external board).
- PCB (blank): HeRo v2 main board where all components are mounted. If you still need to fabricate it, see PCB Order. (https://verlab.github.io/hero_common/pcb_order/)


## C. Soldering Order (SMD → THT)

Reading time: 10 min
Building time: 90 min

Use this exact order to minimize rework. Place parts, tack two pads, refl ow with fl ux. Red means where to put the solder.

1. Small passives: C0603 → R0805 (C1–C2, C3–C4 optional; R0–R10, R12–R15). Note R11 NM.
2. ICs: TP4056 (optional charger), CD4051, IRLML2502 (orientation dot to pin‑1). Inspect bridges.
3. LEDs: WS2812B (arrow DIN/DOUT orientation, aligned to silk polarity). Brief continuity test to check soldering quality.

4. Status LEDs: STDBY (G), CHRG (R) aligned to silk polarity.
5. Connectors/Switch: JST‑PH‑2 ×2, 1×4 female (I²C|UART), 1×3 males (E/M) x4, 1×16 female (ESP) x2, slide switch.


6. Sensors: TCRT5000L ×8 (uniform standoff and coplanarity; align gap to line‑track direction).

7. Step‑up module (MT3608) — PRE‑TUNE ONLY: Off‑board, trim the module to 5.00 V (bench PSU current‑limited; no load or light dummy load). Do not solder to the PCB yet.
a. PSU → module input: PSU + to VIN+, PSU GND to VIN− on the MT3608.
b. Multimeter (DC volts) → module output: Red probe to VOUT+, black probe to VOUT−. Confi rm meter is on V (not A/Ω).
c. Optional second meter (if available): measure PSU input current in series with VIN+ for sanity checks.
d. Procedure:
1. Set bench PSU to 4.0 V, current limit 0.30 A. Power the module.
2. Measure VOUT+/VOUT− with the DMM.
3. Turn the trimpot (typically CCW ↑Vout). Approach 5.00 V slowly; avoid overshoot.
4. Add dummy load and re‑trim under load:
- Light check: 100 Ω (≈50 mA)
- Robot check: 6.2 Ω (≈0.8 A) or 5 Ω (≈1.0 A) only in short bursts to confi rm stability.
5. Observe input current as sanity check:
I_in ≈ (V_out·I_out)/(V_in·η) → for 5 V·1 A @ 3.7 V and η≈0.85 ⇒ ~1.6 A in (beyond small modules for continuous use). If the module overheats or sags, derate to ≤0.8 A or upgrade the converter.
6. Power off. Mark the module “5 V”.
7. Secure the trim: place a small drop of clear nail polish or low‑strength (blue) threadlocker on the trimpot screw to prevent drift. Avoid high‑strength grades; ensure the sealant is non‑conductive and keep it off pads.
8. Solder step‑up module: Verify VIN/VOUT polarity and footprint, then solder the pre‑tuned module to the PCB. Inspect joints and clearance.

## D. Post‑Assembly Electrical Checks

Reading time: 3 min
Building time: 10 min
- Continuity (unpowered): GND plane integrity; 0Ω jumpers R9/R15; no shorts 5 V↔GND, 3V3↔GND.
- Power‑up (bench PSU or Battery): set 5.0 V/0.3 A limit → switch ON → quiescent draw note. No component overheating.


- LED test: drive WS2812B with simple test pattern (rainbow or blink).


- I²C pull‑ups: verify ~4.7 kΩ to 3V3; scan bus → MPU6050 ACK.
- MUX: exercise CD4051 channels with test script; check IR phototransistor voltages with a white/black card.

## E. Firmware bring‑up (smoke test – optional)


Reading time: 3 min
Building time: 30 min

Flash minimal fi rmware on ESP8266 (blink WS2812B, I²C scan, print ADC across IR channels via 4051). Ensure UART via CP2102, Wi‑Fi AP boots. Repository tests are here: (https://github.com/verlab/hero_common/tree/noetic-devel/hero_firmware/tests)

# Part II — Robot Assembly

Reading time: 45 min
Building time: 110 min

## A. Printed/Off‑the‑Shelf Parts

Reading time: 3 min
Building time: 0 min
- Materials & BOM: https://verlab.github.io/hero_common/materials/
- 3D printed parts (STLs & guidance): https://verlab.github.io/hero_common/printing/
- Print tips: 200 µm layer height; PLA/ABS recommended; deburr holes; lightly sand mating faces; verify fi t before fi nal assembly.

Printed set (checklist):

Castor wheel: Screw-on castor wheel for robot balance adjustment. Chassis B: Chassis that supports the mainboard and encoders; Chassis A: Chassis that supports the motors and wheels;
Cover: Dust protection cover;
Cover usb: Sliding part for access to the USB connector;
E-hat: e-hat component to enclose mainboard expansions;
E-hat glove: Adapters for e-hat component;
Encoder shaft: Spur gear/shaft encoder for wheel-encoder transmission; Motor gear: Coupled to the servo motor shaft and acts directly on the wheel; Motor shaft: Wheel shaft supports the connection of the wheel to the chassis; Wheel: Wheel spur geared;.

Off‑the‑shelf:

Drive: SG90 continuous‑rotation servos ×2 (w/ horns & screws) Locomotion: O‑ring tires ×2, 623ZZ bearings ×2
Support: steel balls 4 mm ×2 (casters)
Fasteners: M2.5 self‑tapping screws, assorted M3 screws/nuts/washers Electronics: Li‑Po 103450 (1S), pcb board, IMU sensor, encoders sensor

## B. Main Assembly Sequence

Reading time: 35 min
Building time: 110 min
1. Caster wheels: take the printed caster shell; insert a 4 mm steel ball into the cup. Use pliers to gently crimp the rim just enough to retain the ball while keeping free rotation.


2. Mount casters to Chassis A: align the two casters to the front/back positions on Chassis A and fasten with the specifi ed screws. Confi rm ground clearance and smooth swivel.
3. Prepare motors (SG90 CR -⚠️ if needed): ideally purchase SG90 servos already adapted for continuous rotation, since most stock SG90 units are angular‑limited.

⚠️ Be aware there are different internal variants (encoder types) even with the same SG90 form factor. The green‑label variant is recommended, as it allows easy CR adaptation without replacing resistors or other components.

🔧 If you only fi nd a standard (non‑CR) type, follow a trusted tutorial such as this video (https://www.youtube.com/watch?v=4Z-j6bUJTQ8) to perform the continuous‑rotation modifi cation. After confi rming CR function, power the servo and send ~1500 µs to center it. Then trim/select the horn that best seats in the printed gear adapter.

4. Couple the motor gear to the servo shaft (gear adapter method):
a) After converting the servo for continuous rotation (if needed), choose a stock servo horn that best fi ts inside the printed motor gear/adapter. Cut the horn, leaving only the cylindrical hub/connector.

⚠️ Attention: wear safety glasses when cutting, as small plastic pieces can eject unexpectedly and pose a risk to eyes or face.


c) Trim the cylindrical hub evenly until it press‑fi ts into the printed motor gear (snug, not loose). Then, apply a small drop of cyanoacrylate (super glue) at the interface to lock the hub in the gear; avoid exces s glue near teeth.

⚠️ Attention: handle super glue carefully to avoid contact with eyes, mouth, or skin; always work in a ventilated area and use protective equipment if possible.

e) If the servo shaft protrudes, shorten ~1.00–1.20 mm so the gear sits as close as possible; make the cut fl at (fi le if needed).

⚠️ Attention: when cutting the shaft with a precision knife, wear gloves and keep the cut clean and perpendicular. Work slowly to avoid slipping and damaging the plastic housing or injuring yourself or others nearby.

f) Fasten the gear/hub to the servo output with the original horn screw from the servo kit.

🔧 Tips: After fastening, avoid overtightening the horn screw—too much torque increases friction and can damage the gear interface. Connect the servo to the board (or any PWM controller) and run it in both directions to check constant smooth rotation. Adjust screw tightness until rotation is stable. Lightly press the gear by hand to ensure the glue bond holds. The fi t must be neither too tight nor too loose; gear teeth should drive the wheel smoothly with minimal backlash.

5. Install motors on Chassis A: position each servo in its printed mount on Chassis A and fasten. Verify both outputs are aligned when commanded to stop (1500 µs).


🔧 Tip: do not overtighten the mounting screws—leave them slightly loose to allow a bit of
fl exibility in the shaft‑to‑wheel transmission. Carefully align both motors on each side for proper symmetry. Trim motor cables to about 10 cm length to simplify cable routing inside the robot.

6. Build wheels: press‑fi t a 623ZZ bearing into each printed wheel hub (use a vise/press; avoid striking directly—if needed, tap gently through a fl at spacer). Fit the O‑ring tire around the rim.


7. Install wheels & support screw: place the wheel onto the gear adapter/output, add the designated support screw/axle on the opposite side if your design uses one, and secure. The gear mesh between motor gear and wheel should be smooth with minimal backlash.

⚠️ Attention: the 3D-printed shaft sleeve that couples the screw and the motor shaft must allow the wheel to rotate smoothly with almost no backlash. Ensure a tight but precise fi t—avoid wobble, as it is critical for proper transmission.

🔧 Tip: add a tiny drop of glue to the support screw where it threads into Chassis A, to prevent it from loosening or falling out during handling and wheel installation.

8. Battery placement & routing: mount the Li‑Po between Chassis A and B (in the battery cradle). Route the JST cable up to the electronics bay on top of Chassis B; secure with ties.

⚠️ Attention: observe the labels on Chassis B ("USB" and "Front"). Always pass the battery cable through the USB hole and the motor cables through the Front hole to ensure safe and clean routing.


9. Add Chassis B (upper): stack Chassis B over Chassis A and secure with four screws.


10. Prepare the quadrature encoder: use a mouse‑style mechanical quadrature encoder. Remove the lateral metal spring/detent to eliminate the tactile "clicks" (bend or cut the spring carefully) so rotation is smooth. Solder a JST‑PH pin header to the encoder terminals for easy wiring.

⚠️ Attention: when cutting or trimming the encoder shafts, wear safety glasses and protective gloves to prevent small parts from ejecting and injuring yourself or others nearby. Always direct the cutting tool away from people, and keep bystanders clear.


🔧 Tip: cut the encoder pins/shafts as precisely as possible to the required length. When bending or disabling the detent, verify that the shaft rotates completely smooth, with no tactile steps—any residual friction can cause missed counts or noisy readings. For wiring, solder a JST‑PH female header to the encoder terminals, trimming it to the correct size so it fi ts cleanly into the PCB connector.

11. Install encoder into Chassis B: insert the encoder into its pocket on Chassis B directly above the wheel position.


🔧 Tip: after assembling the encoder with its shaft and small gear, gently rotate the encoder shaft to verify smooth rotation. It must not bind or create excess friction, and it should not be too loose either. Check for lateral play: the shaft should not wobble vertically or transversely—aim for a fi rm but smooth fi t. If, later on, the motor-wheel-encoder transmission does not run smoothly, lightly sand the gears to improve meshing and reduce backlash.

12. Controller board: mount your controller (ESP8266/NodeMCU) on standoffs above Chassis B.
13. Top cover: place the protective cover over the assembly and secure it with eight screws. Be careful not to overtighten—use moderate torque so screws seat but don’t crack plastic.

⚠️ Also ensure no screw penetrates or presses on the battery beneath; a mislocated or oversize screw may pierce the Li-Po and cause a short or fi re risk.


14. Final wheel installation and coupling with encoder: insert the wheel onto the shaft from Chassis B at this stage (although wheels can be temporarily fi tted earlier for local tests).

🔧 Tip: Secure with the proper screw, ensuring the gear train from motor → wheel → encoder runs smoothly with minimal backlash. Gently turn the wheel by hand at low force to check for pendulum or wobble. If rotation is rough or too tight, lightly sand the gear teeth for a better fi t. The transmission should remain coaxial, smooth, and free of binding.

15. Electrical connections: plug both servo leads (signal to PWM, red to 5 V, brown/black to GND) and the battery JST into the main PCB. Seat the PCB into its mounts as shown in the fi gure, and double‑check polarity and strain relief.

⚠️ Attention: never connect the plugs inverted; a reversed connection may damage the battery, motors, or sensors.


16. E‑hat module: solder male header pins onto the IMU board (gyro+accelerometer). Mount the IMU securely into the 3D‑printed e-hat case with small screws as shown in the fi gure. Then fasten the printed e-hat case above the PCB board. The header pins should align so the I²C and power lines plug directly into the I²C connector on the main PCB.


17. Final mechanical check: wheels free‑spin, encoder linkage aligned, casters swivel, no cable rub. Proceed to Part III for calibration.

## C. Troubleshooting

Reading time: 5 min
Building time: 0 min

Common issues & fi xes:

- Motors not spinning / weak torque: check servo wiring (PWM–5 V–GND), confi rm boost module is holding 5 V under load, verify battery voltage >3.6 V.
- Wheels wobble or backlash excessive: re‑seat wheel hub, ensure bearings are fully pressed, lightly sand or shim gear adapter for tighter fi t.
- Encoder counts intermittent: confi rm detent spring fully removed, check JST‑PH header solder joints, verify no lateral wobble on shaft.
- IR sensors not responding: check orientation, LED polarity, and verify current‑limiting resistors populated.
- Board does not power: double‑check MT3608 tuned to 5.0 V, confi rm JST polarity (never reverse Li‑Po), inspect switch soldering.
- Overheating boost converter: load >1 A continuous; derate to ≤0.8 A or upgrade module, add heatsink if needed.

# Part III — Software Setup & Programming

Reading time: 60 min
Building time: 105 min

## A. Installation (Docker or source)

Reading time: 10 min
Building time: 30 min

Setting up the HeRo software environment is an essential step before you can calibrate or program the robot. You have two main paths: an easier Docker-based installation, or a manual build from source. Both approaches share the same software dependencies.

️ Dependencies
You will need to have the following software available:
- ROS (tested with Melodic and Noetic)
- rosserial for microcontroller communication
- Gazebo for simulation
- Qt for GUI tools
- Arduino IDE (only required if you plan to fl ash fi rmware directly)

📦 Method 1 — Docker (recommended for beginners)
Docker provides a contained environment with all the dependencies already packaged, which reduces compatibility issues and setup time.
1. Install Docker if not already present. Follow the official guide. (https://docs.docker.com/get-docker/)
2. Clone the repository to your machine:

$ git clone https://github.com/verlab/hero_common.git

3. Go to the directory:

$ cd hero_common/hero_common

4. Build the container with Docker Compose:

$ docker compose up ros1 -–build # for ROS 1 (Noetic) or

$ docker compose up -–build # for ROS 2 (Foxy)

⚠️ ROS 2 compatibility is still limited. You can still run the package on ROS 1 and bridge to ROS 2 using ros1_bridge.

After building, you can launch the containers and interact with ROS nodes as if you were running them locally, but without dependency confl icts.

💻 Method 2 — Build from Source (for advanced users)
If you prefer direct control, or you plan to modify the source code extensively, you can set up the packages in your own ROS workspace.
1. First, make sure you have a catkin workspace confi gured (e.g., ~/catkin_ws). If not, follow the ROS installation guide (http://wiki.ros.org/ROS/Installation) and environment confi guration tutorial. (http://wiki.ros.org/ROS/Tutorials/InstallingandConfiguringROSEnvironment)
2. Clone the repository into your src folder:

$ cd ~/catkin_ws/src

$ git clone --depth 1 --branch noetic-devel https://github.com/verlab/hero_common.git

3. Resolve dependencies with rosdep:

$ cd hero_common/hero_common

$ rosdep install --from-paths src/hero_common --ignore-src -r -y

4. Compile the workspace:

$ catkin_make # or catkin build

5. Source your workspace so the packages are available:

$ source devel/setup.bash

✨ Tips and Recommendations

- Docker is the fastest way to get started if you just want to run the robot and simulations without tinkering too much.
- Source builds are more fl exible if you intend to dive into development or debugging.
- Always confi rm your ROS distro matches the branch you checked out (e.g., melodic-devel, noetic-devel).
- Keep rosdep updated regularly with rosdep update.
- Consider setting source devel/setup.bash in your ~/.bashrc to load your workspace automatically when opening a terminal.

## B. Firmware (Arduino/ESP8266)

Reading time: 20 min
Building time: 30 min

Flashing the HeRo fi rmware is required for the robot’s ESP8266-based controller to communicate with ROS and execute commands. This process involves setting up the Arduino IDE with the correct board support, drivers, and project fi les.

🔧 Step 1 — Install Arduino IDE
Download and install the latest Arduino IDE from the official website. The IDE provides the compiler and uploader required to burn fi rmware onto the ESP8266.

🔧 Step 2 — Install USB Driver
Most Linux distributions already include the CP2102/CH340 drivers for NodeMCU modules, but on Windows and macOS you may need to install them manually. Ensure the driver is properly installed so your computer recognizes the board.

🔧 Step 3 — Confi gure ESP8266 Board Support

1. Open Arduino IDE → File → Preferences.
2. Add this URL under Additional Boards Manager URLs: http://arduino.esp8266.com/stable/package_esp8266com_index.json
3. Restart the IDE.
4. Go to Tools → Board → Boards Manager → search for esp8266 and install version 2.5.0 (recommended for compatibility).


5. From Tools → Board, select NodeMCU 1.0 (ESP-12E Module). Confi rm the other default settings (160 MHz, 4M/3M SPIFFS, 115200 baud).

⚠️ Attention: Installing other versions of the ESP8266 core may cause incompatibility. Stick to 2.5.0 unless you know what you are doing.


🔧 Step 4 — Open HeRo Firmware Project

1. In Preferences, set the Sketchbook location to the firmware folder inside the cloned hero_common repository.
2. Restart the IDE and open the HeRo fi rmware sketch.
3. Review config.h for parameters such as Wi-Fi SSID, password, and robot ID.
- Tip: avoid editing dynamic parameters directly in config.h. Use the built-in web interface after fl ashing for changes.

🔧 Step 5 — Upload Firmware

1. Connect the HeRo board to your computer via USB.
2. In Arduino IDE, select the proper serial port under Tools → Port.
3. Click Upload. The code will compile and be fl ashed to the ESP8266.

⚠️ Attention: Always confi rm battery is disconnected during USB fl ashing to avoid power confl icts.

✨ Tips:

- If upload fails, try lowering the baud rate (e.g., 57600) or resetting the board.
- Keep a backup of config.h with your Wi-Fi and robot ID settings.
- After fl ashing, open the Serial Monitor at 115200 baud to confi rm boot messages.
- Use the fi rmware’s web interface to confi gure Wi-Fi credentials and dynamic parameters without recompiling.

## C. ROS Networking & Bring‑up

Reading time: 10 min
Building time: 15 min

In order to control HeRo robots remotely with ROS, you must confi gure the network parameters so that the ESP8266 connects to your ROS master. This requires setting Wi‑Fi credentials and the ROS master IP/port on the robot.

🌐 Network Setup
HeRo supports only 2.4 GHz Wi‑Fi networks. You can either create a hotspot on your laptop or use a standard Wi‑Fi router. The fi rmware has two operation modes: Confi g Mode and ROS Mode.
- Entering Confi g Mode: Cover all IR sensors and power on HeRo. The RGB LED will fl ash pink. In this mode the robot creates its own Wi‑Fi access point.
- Connecting: On your computer or smartphone, connect to the AP:
- ESSID: HERO_ROBOT_*****
- Password: s3cr3tp4ss
- Once connected, open http://192.168.4.1/ in a browser. Fill in your Wi‑Fi SSID, password, and the ROS master IP/port. Save settings, then turn HeRo off.


🔵 Connecting HeRo to Your Network
Power HeRo on normally. If it connects to Wi‑Fi successfully, the LED blinks blue briefl y. If it fails, it will blink red continuously. Once confi gured, the robot will auto‑connect whenever the network is available. Reconfi gure only if you change Wi‑Fi credentials or ROS master address.

🚀 Launching ROS Nodes
On the ROS master PC, launch the bring‑up fi le:

$ roslaunch hero_bringup hero_bringup.launch

Keep this running. Then power on the robot. If successful, you’ll see connection logs in the terminal.

📡 Available ROS Topics
Check with rostopic list:
- /hero_0/cmd_motor — motor PWM commands
- /hero_0/encoder — encoder feedback
- /hero_0/imu — gyro + accelerometer + orientation

- /hero_0/laser — IR distance sensor array
- /hero_0/led — RGB LED control
- /hero_0/odom — odometry estimation
- /hero_0/position_controller/cmd_vel — position controller
- /hero_0/velocity_controller/cmd_vel — velocity controller
- /tf — HeRo’s TF tree

️ Available Services

- /hero_0/pid_calibration
- /hero_0/set_frequency
- /hero_0/set_odom
- /hero_0/set_pid_parameters

🎮 Teleoperation Demo
Open another terminal and run:

$ roslaunch hero_bringup hero_teleop.launch id:=0

Replace id:=0 with your robot ID. Use keyboard input to drive the robot around and verify connectivity.

⚠️ Attention: Ensure your fi rewall does not block ROS master communication. If using multiple robots, assign unique IDs and confi rm each has a unique IP on the network.

✨ Tips:

- Test connectivity with ping <robot_IP> before launching ROS nodes.
- If connection drops, check Wi‑Fi strength and confi rm the robot is within router range.
- Use rqt_graph to visualize node/topic connections and confi rm the robot is publishing correctly.

## D. Robot Simulation (Gazebo – optional)

Reading time: 20 min
Building time: 30 min

HeRo can be fully simulated in the Gazebo simulator. This is useful for testing algorithms, verifying robot behavior, and developing code before deploying on real hardware.

🧩 HeRo Wizard Interface
A graphical wizard is available to simplify environment creation and robot spawning:
1. Launch the wizard with:
$ roslaunch hero_gazebo gazebo_wizard.launch
2. A GUI will appear alongside Gazebo. From here you can:
- Select an arena from the list.
- Commit or clear the arena in Gazebo.
- Choose the number of robots.
- Enable or disable specifi c sensors.
- Commit the swarm (spawn robots) or clear them.
- Adjust the scene directly in Gazebo.
- Generate a launch fi le for reuse with the confi gured setup.

After setup, you may close Gazebo and the wizard. The generated launch fi le allows you to recreate the same scenario later without going through the wizard again.

🚀 Using Simulation Without Wizard
If you already have a prepared environment or prefer not to use the wizard:

$ roslaunch hero_gazebo gazebo_bringup.launch # starts Gazebo
$ roslaunch hero_gazebo env_spawn.launch # spawns robots + arena

Now the robots are active inside Gazebo. Verify with:

$ rostopic list

You will see topics such as:

- /hero_0/cmd_vel
- /hero_0/laser
- /hero_0/led
- /hero_0/odom
- /hero_1/cmd_vel, etc.
- /joint_states, /tf, /clock, and standard Gazebo topics.

⚙️ Features Available in Simulation

- Differential drive controller
- Odometry
- IMU data
- IR proximity sensors (simulated as laser beams)

⚠️ Attention: Simulation can be resource-intensive. Ensure your system has adequate CPU/GPU support and avoid running too many robots simultaneously if performance drops.

✨ Tips:

- Use rqt_graph to confi rm simulated topics are active before running control code.
- Save frequently used scenarios as launch fi les to avoid repeating setup.
- Test control strategies in simulation before deploying to hardware to minimize risk.
- A short video tutorial is available here. (https://www.youtube.com/watch?v=IO7FPEwkZkE)

# Part IV — Calibration

Reading time: 25 min
Building time: 60 min

Calibration is essential to ensure that HeRo operates smoothly and predictably. This section details how to confi gure motor PWM, tune controllers, and calibrate the IR distance sensors.

## A. Enter Confi guration Mode

Reading time: 5 min
Building time: 5 min

To access calibration mode, launch HeRo in confi guration mode instead of the standard bring-up mode:

$ roslaunch hero_bringup hero_confmode.launch

When in confi g mode, the robot exposes extra ROS services for calibration. Verify that the expected topics and services appear:

$ rostopic list
- /diagnostics
- /hero_2/cmd_motor
- /hero_2/encoder
- /hero_2/imu
- /hero_2/laser
- /hero_2/led
- /hero_2/odom
- /hero_2/position_controller/cmd_vel
- /hero_2/velocity_controller/cmd_vel
- /rosout
- /rosout_agg
- /tf

$ rosservice list
- /hero_2/ir_calibration
- /hero_2/motors_parameters
- /hero_2/position_controller/pid_calibration
- /hero_2/position_controller/pid_parameters
- /hero_2/set_odom
- /hero_2/velocity_controller/pid_calibration
- /hero_2/velocity_controller/pid_parameters
- /hero_bringup/get_loggers
- /hero_bringup/set_logger_level
- /rosout/get_loggers
- /rosout/set_logger_level

## B. Motor PWM Calibration

Reading time: 5 min
Building time: 10 min

The SG90 continuous servo motors are controlled with PWM signals. In theory, 1500 µs should stop the motor, while values around 1000 µs and 2000 µs rotate in opposite directions. In practice, the neutral value varies per motor.

Steps:

1. Run RQT and use Plot to visualize wheel speed.
2. Use Easy Message Publisher to send PWM values incrementally.
3. Find the exact PWM values where each wheel stops without jitter.


Example command to save calibration:

$ rosservice call /hero_2/motors_parameters "left_motor_pwm: 1493 right_motor_pwm: 1448"

## C. Position Controller PID

Reading time: 2 min
Building time: 10 min
After PWM calibration, tune the PID that controls wheel position.

$ rosservice call /hero_2/position_controller/pid_parameters "{lkp: 5.0, lki: 9.0, lkd: 0.1, rkp: 5.0, rki: 9.0, rkd: 0.1}"

These defaults provide good response, but you can fi ne-tune empirically.

## D. Velocity Controller PID

Reading time: 2 min
Building time: 10 min

The velocity controller uses another PID loop for smooth speed control. Example tuning:

$ rosservice call /hero_2/velocity_controller/pid_parameters "{lkp: 1200.0, lki: 2300.0, lkd: 0.1, rkp: 1200.0, rki: 2300.0, rkd: 0.1}"

Again, start with defaults and adjust slightly if needed.

## E. IR Distance Sensor Calibration

Reading time: 10 min
Building time: 20 min

The IR proximity sensors require calibration to provide reliable range estimation. This is done via the ROS service /hero_*/ir_calibration.

Manual calibration procedure:

1. Place an object (preferably white) at a known distance d from the IR sensor.
2. Run:
$ rostopic echo /hero_*/laser
to read the intensity.


3. Compute calibration parameter as: calibration = intensity × d²
4. Repeat for all 8 sensors.
5. Save values with:
$ rosservice call /hero_*/ir_calibration "{IR0: 0.39, IR1: 0.28, IR2: 0.45, IR3: 0.29, IR4: 0.52, IR5: 0.22, IR6: 0.23, IR7: 0.28}"

Alternative batch method:

- Place 8 objects at the same distance in front of all sensors.

- Use the provided calibration script:
$ rosrun hero_examples hero_ir_calib.py hero_*
- A 3D‑printed alignment tool (https://github.com/verlab/hero_common/tree/noetic-devel/hero_resources/3d_parts/ir_calibration) is available to simplify this step.

IR Sensor Test:
If calibration fails, test the hardware:
- Use cellphone camera/webcam to check IR LED emission (should glow purple).
- With a multimeter, measure voltage variation across the phototransistor while covering/uncovering it.


- Replace faulty TCRT5000 sensors if no variation is detected.

⚠️ Attention: Wear protective glasses when cutting sensor legs or handling tools. Always keep the robot on a stable surface during calibration.

✨ Tips:

- Perform calibration in consistent lighting conditions.
- Avoid refl ective or very dark surfaces during calibration.
- Re‑calibrate after hardware changes or sensor replacement.
- Video expected behavior here. (https://private-user-images.githubusercontent.com/14208261/218348064-9638f3d9-a66f-43f9-814f-426c5cd91aa5.mp4)
- Video for manual calibration here. (https://private-user-images.githubusercontent.com/14208261/218351257-2bc2767a-8aff-4ed9-b512-e373bce10820.mp4)
- Video with fallback test using other RangeSensor fi rmware here. (https://private-user-images.githubusercontent.com/14208261/218352369-a99e7c69-c070-4dcd-ba82-57c5e348644f.mp4)

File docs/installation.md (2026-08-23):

---
layout: page
title: Install ROS
permalink: /installation/
section: software
lead: Step 1 of 4. Clone the catkin workspace, then pick Docker or compile from source. Tested on ROS 1 Melodic and Noetic.
---

## What you need

- [ROS 1](http://wiki.ros.org/ROS/Installation) — Melodic or Noetic
- [rosserial](http://wiki.ros.org/rosserial)
- [Gazebo](https://gazebosim.org/home) and [Qt](https://www.qt.io/) if you will run the **Gazebo** simulator later
- Python 3.10–3.13 if you will run **[Genesis World]({{ '/robot_simulation/#genesis-world' | relative_url }})** (NVIDIA CUDA recommended; CPU works)

The Arduino IDE is only needed in the next step, when you flash the ESP8266.

## Docker

If Docker is not installed yet, follow the [NVIDIA container toolkit guide](https://docs.nvidia.com/datacenter/cloud-native/container-toolkit/install-guide.html) (or the official Docker docs).

Clone the repository and build the ROS 1 image:

```sh
$ git clone https://github.com/verlab/hero_common.git
$ cd hero_common/hero_common
$ docker-compose build ros1
```

## Build from source

If you do not have a catkin workspace yet, follow the [ROS install](http://wiki.ros.org/ROS/Installation) and [workspace](http://wiki.ros.org/ROS/Tutorials/InstallingandConfiguringROSEnvironment) tutorials, then clone into `src`:

```sh
$ cd ~/catkin_ws/src
$ git clone --depth 1 --branch noetic-devel https://github.com/verlab/hero_common.git
```

Install dependencies and compile:

```sh
$ cd ~/catkin_ws
$ rosdep install --from-paths src/hero_common --ignore-src -r -y
$ catkin_make
$ source devel/setup.bash
```

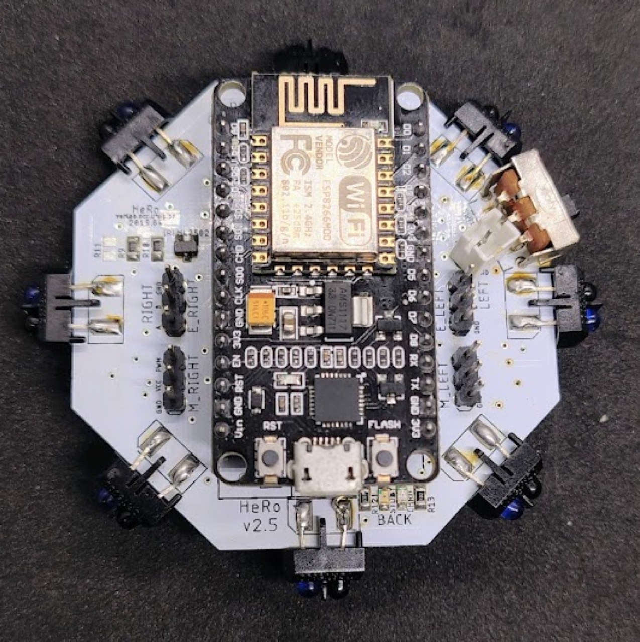
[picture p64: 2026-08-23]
docs/assets/img/build/image58.jpg

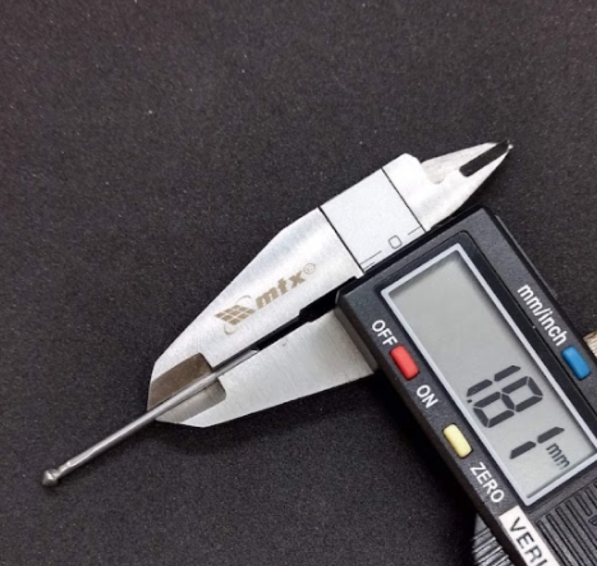
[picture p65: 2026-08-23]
docs/assets/img/build/image98.jpg

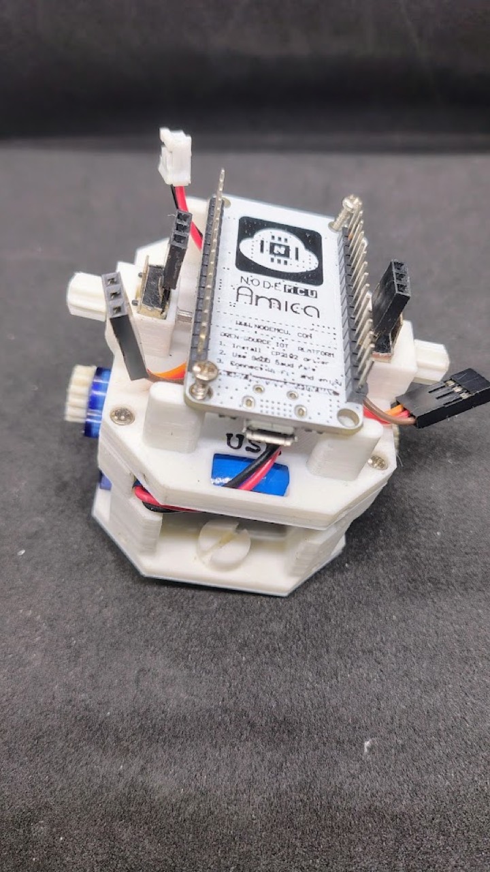
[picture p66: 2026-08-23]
docs/assets/img/build/image99.jpg

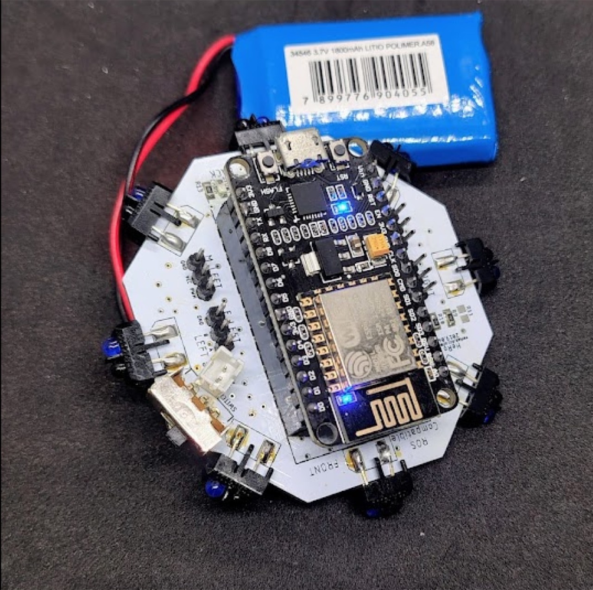
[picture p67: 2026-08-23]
docs/assets/img/build/image88.jpg

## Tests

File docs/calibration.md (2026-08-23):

---
layout: page
title: Calibration
permalink: /calibration/
section: build
lead: Motors, PID gains, and IR distances are tuned over ROS services. The paper notes that cheap parts need occasional IR and motor calibration, per sensor and per wheel.
---

# Summary
- [Enter Configuration Mode](#Enter-Configuration-Mode)
- [Motor PWM Calibration](#Motor-PWM-Calibration)
- [Position Controller PID](#Position-Controller-PID)
- [Velocity Controller PID](#Velocity-Controller-PID)
- [IR Distance Sensor](#IR-Distance-Sensor)

# Enter Configuration Mode
To be able to access calibration mode, run launch file ```hero_confmode.launch``` instead of file ```hero_bringup.launch```.
```sh
$ roslaunch hero_bringup hero_confmode.launch
```

```sh
... logging to /home/rezeck/.ros/log/4d1fdafe-8eb9-11ed-b4a8-e454e82b3305/roslaunch-rezeck-28550.log
Checking log directory for disk usage. This may take a while.
Press Ctrl-C to interrupt
Done checking log file disk usage. Usage is <1GB.

xacro: in-order processing became default in ROS Melodic. You can drop the option.
Deprecated: xacro tag 'property' w/o 'xacro:' xml namespace prefix (will be forbidden in Noetic)
when processing file: /home/rezeck/catkin_ws/src/hero_common/hero_description/urdf/common.xacro
included from: /home/rezeck/catkin_ws/src/hero_common/hero_description/robot/hero.urdf.xacro
Use the following command to fix incorrect tag usage:
find . -iname "*.xacro" | xargs sed -i 's#<\([/]\?\)\(if\|unless\|include\|arg\|property\|macro\|insert_block\)#<\1xacro:\2#g'

started roslaunch server http://rezeck:39447/

SUMMARY
========

PARAMETERS
 * /description: <?xml version="1....
 * /hero_bringup/fork_server: False
 * /hero_bringup/port: tcp
 * /hero_bringup/tcp_port: 11411
 * /rosdistro: melodic
 * /rosversion: 1.14.13

NODES
  /
    hero_bringup (rosserial_python/serial_node.py)

auto-starting new master
process[master]: started with pid [28585]
ROS_MASTER_URI=http://localhost:11311

setting /run_id to 4d1fdafe-8eb9-11ed-b4a8-e454e82b3305
process[rosout-1]: started with pid [28607]
started core service [/rosout]
process[hero_bringup-2]: started with pid [28610]
[INFO] [1673116204.495423]: ROS Serial Python Node
[INFO] [1673116204.507878]: Fork_server is: False
[INFO] [1673116204.510605]: Waiting for socket connections on port 11411
[INFO] [1673116204.513295]: Waiting for socket connection
[INFO] [1673116211.760987]: Established a socket connection from 10.42.0.100 on port 53937
[INFO] [1673116211.764608]: calling startSerialClient
[INFO] [1673116213.872803]: Requesting topics...
[INFO] [1673116213.877849]: [/hero_2] Firmware: v3.5 | Hardware: v2.5 | Config: v2.3 | IP: 10.42.0.100 
[INFO] [1673116213.882569]: [/hero_2] IMU is not working or not connected! Error: 1
[INFO] [1673116213.887142]: [/hero_2] Conected at time 5970
[INFO] [1673116213.899679]: [/hero_2] Conected at time 6976
[INFO] [1673116214.092311]: Note: publish buffer size is 4096 bytes
[INFO] [1673116214.093081]: Setup publisher on /hero_2/laser [sensor_msgs/LaserScan]
[INFO] [1673116214.096119]: Setup service server on /hero_2/ir_calibration [hero_common/SetIRCalibration]
[INFO] [1673116214.098496]: Setup publisher on /hero_2/imu [sensor_msgs/Imu]
[INFO] [1673116214.101250]: Setup publisher on /hero_2/encoder [hero_common/Encoder]
[INFO] [1673116214.388237]: Setup publisher on /tf [tf/tfMessage]
[INFO] [1673116214.402824]: Setup publisher on /hero_2/odom [nav_msgs/Odometry]
[INFO] [1673116214.405288]: Setup service server on /hero_2/set_odom [hero_common/SetOdom]
[INFO] [1673116214.407618]: Setup service server on /hero_2/motors_parameters [hero_common/SetMotor]
[INFO] [1673116214.409854]: Setup service server on /hero_2/position_controller/pid_parameters [hero_common/SetPID]
[INFO] [1673116214.415074]: Setup service server on /hero_2/position_controller/pid_calibration [std_srvs/Trigger]
[INFO] [1673116214.417548]: Setup service server on /hero_2/velocity_controller/pid_parameters [hero_common/SetPID]
[INFO] [1673116214.420146]: Setup service server on /hero_2/velocity_controller/pid_calibration [std_srvs/Trigger]
[INFO] [1673116214.422874]: Note: subscribe buffer size is 4096 bytes
[INFO] [1673116214.423638]: Setup subscriber on /hero_2/led [std_msgs/ColorRGBA]
[INFO] [1673116214.428581]: Setup subscriber on /hero_2/cmd_motor [hero_common/Motor]
[INFO] [1673116214.432390]: Setup subscriber on /hero_2/position_controller/cmd_vel [geometry_msgs/Twist]
[INFO] [1673116214.437566]: Setup subscriber on /hero_2/velocity_controller/cmd_vel [geometry_msgs/Twist]
[INFO] [1673116214.911270]: [/hero_2] Conected at time 7978
```

After running the launch, verify that the robot has connected and that the following topics and services are available:
```sh
$ rostopic list 
```

```sh
/diagnostics
/hero_2/cmd_motor
/hero_2/encoder
/hero_2/imu
/hero_2/laser
/hero_2/led
/hero_2/odom
/hero_2/position_controller/cmd_vel
/hero_2/velocity_controller/cmd_vel
/rosout
/rosout_agg
/tf
```

```sh
$ rosservice list 
```

```sh
/hero_2/ir_calibration
/hero_2/motors_parameters
/hero_2/position_controller/pid_calibration
/hero_2/position_controller/pid_parameters
/hero_2/set_odom
/hero_2/velocity_controller/pid_calibration
/hero_2/velocity_controller/pid_parameters
/hero_bringup/get_loggers
/hero_bringup/set_logger_level
/rosout/get_loggers
/rosout/set_logger_level
```

# Motor PWM Calibration
The way to control the robot's motors is through the PWM technique, which allows controlling the voltage in the motor. The PWM range for the SG90 servo motor allows us to control the speed and direction of the wheel. In theory, the PWM range is 1000-2000 ms, and 1500 ms should have the motor stopped. In practice, this range can vary and does not have a linear behavior with respect to speed.

In this calibration step, we just need to find the PWM value at which the motor stops completely.

The best way to do this is to open the rqt viewer and configure it to visualize the wheel speed using the Plot tool and also open the easy message publisher tool, as in the figure below. Use this tool through the slide bar to send PWM commands to each motor. Try to position the slides so that the wheels are completely stopped and there is no jitter noise coming from the motors.

```sh
$ rosrun rqt_gui rqt_gui
```



After finding these two values, use the following command to calibrate the motors. Use the values you found in this process.
```sh
$ rosservice call /hero_2/motors_parameters "left_motor_pwm: 1493 right_motor_pwm: 1448"
```
```sh
success: True
message: "Motor Parameters has been succesfully recorded!"
```

# Position Controller PID
After calibrating the motor PWM, we can calibrate the PID controller which will control the desired wheel position. This process is empirical and can be tuned using the following command:
```sh
$ rosservice call /hero_2/position_controller/pid_parameters "{lkp: 5.0, lki: 9.0, lkd: 0.1, rkp: 5.0, rki: 9.0, rkd: 0.1}"
```

```sh
success: True
message: "PID Parameters has been succesfully recorded!"
```
These values have a good response, so if you don't need to refine the controller, you can leave it as it is or try small variations.

# Velocity Controller PID
Similarly, we use a PID controller to control the speed of the robot's wheels. To tune the parameters, use the following command:
```sh
$ rosservice call /hero_2/velocity_controller/pid_parameters "{lkp: 1200.0, lki: 2300.0, lkd: 0.1, rkp: 1200.0, rki: 2300.0, rkd: 0.1}"
```

```sh
success: True
message: "PID Parameters has been succesfully recorded!"
```
These values have a good response, so if you don't need to refine the controller, you can leave it as it is or try small variations.

# IR Distance Sensor

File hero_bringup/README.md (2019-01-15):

# HeRo brignup Server

This package bringup rosserial tcp server to connect the robots with ROS.

## How to use
- Connect the robot on the same network where your computer is.
- Open the terminal and type the following command. This launch file calls the rosserial python server.

```sh
$ roslaunch hero_bringup hero_bringup.launch
```

## Teleoperation
- To remotely control the robot, use the following command. It's important to set the id of the robot by using the arguments id.
- Use the keyboard to control the robot. Use the keys w/x to decrease the linear speed to less than 0.25 cm/s and the keys e/c to adjust the angular speed.

```sh
$ roslaunch hero_bringup hero_teleop.launch id:=0
```

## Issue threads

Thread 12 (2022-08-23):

Is MT3608 required to assemble Hero2.0?

Suptree, 2022-08-23:
Thank you for developing Hero2.0.

I am planning to use it in the future for my research on swarm robotics.

Currently, I am assembling Hero2.0 based on the parts listed in assembly_materials.pdf.

And I am trying to join the PCB Board (v2.6) and MT3608.

However, the sizes do not match.

I looked at cad(https://a360.co/36zKPdi) and found that MT3608 is not used.

Is MT3608 listed in assembly_materials.pdf not used?

Also, what should we use as a replacement component?

I am not an expert in the mechanical field, so please be gentle and let me know.

best regards, and thank you in advance for your help.

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

rezeck, 2022-08-31:
Hi @Suptree

Thank you for considering this robot in your projects!

We recently switched from [another module](https://www.sparkfun.com/products/retired/8290) to this one, so the hero board is not fully compatible (sorry for this issue). I will update the board schematic soon!

However, I recommend using the MT3608 since it can provide (theoretically) 2A, which is more than enough for the robot allowing power other modules (e-hats).

In this step, try to adjust the MT3608's potentiometer (and fix it with some glue) so that the output voltage is at 4.90V. Some WS2812 LEDs do not work properly at voltage > 5.0V.

To install it on your board version, we solder a cable (>= 24 AWG) as a connector between the board and the module. The module should fit below the nodemcu board and the hero board (as in the figure below).

Any questions, feel free to contact me.

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

rezeck, 2022-08-31:
Hi @Suptree

I just noticed that some of the IR sensors are soldered upside down. As a guide, try to align the top view of the IR sensor with the drawing on the board. That chamfer should line up with the one drawn on the board.

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

Best regards

Suptree, 2022-08-31:
Hi @rezeck

Thank you for the clear explanation.

Okay, I will use AWG24 cable to bind the board to the MT3608 until the latest version of Hero borad is released.

Thanks for pointing out the IR sensor. I was not aware of it.

We will contact you if we have any further questions.

wt160, 2022-10-02:
Hi, @rezeck:
Great work on the robot!
Just to say hi and show you guys there are people out here trying to build the robot.
I met the same issue, will try the solution mentioned above, but still hope you may update the  board schematic.
Thanks in advance!
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

rezeck, 2022-10-09:
Hi @wt160 and @Suptree,

Sorry for my delay. Unfortunately, it's hard to find time to focus on improving HeRo. But whenever possible, I try to fix or improve some points.

I just committed a new version (v2.7) of the PCB with support for MT3608, and I also positioned the battery charging status LEDs to improve the visualization. More information [here](https://verlab.github.io/hero_common/pcb_order/).

Unfortunately, I didn't have time to test this new version properly, but I believe everything is working fine. If you find some issues, please let me know.

@wt160 I liked the PCB with the purple mask! It's very cool!

Thank you so much for considering this robot for your projects! =)

wt160, 2023-01-02:
Hi, Rezeck:
I have used the v2.7 design, the board is like this.
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
Could you help me to check whether the TCRT5000 alignment is correct?
You posted a picture above, but I am not sure whether the green one is correct, or the red one is correct.

Thanks!
Wei

rezeck, 2023-01-05:
Hi @wt160,

Sorry for the late reply! I hope I've been able to keep up with the development.

It seems to me that you have to invert all the TCRT5000, as they are upside down.

The photodiode (light blue led) must be aligned with that chamfer drawn on the board. The TCRT5000's plastic case, when viewed from above, has a chamfer on the side of the photodiode. So the idea is to align the chamfer on the case with the one in the board. Perhaps this figure will help you visualize.

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

Another tip, check if the TCRT5000 pull-down resistor is connected to the phototransistor (dark led).

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

Please let me know if it works for you.
Regards,
Rezeck

wt160, 2023-01-07:
Hi, Rezeck:

Thank you for your reply! The pictures are really helpful. I will try the correct way.

Best,
wt160

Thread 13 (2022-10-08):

Could you please tell me how to assemble the servo motor and rotary encoder?

Suptree, 2022-10-08:
Thank you for your response the other day.
Thanks to your help, I was able to attach all the electronic components to the PCB board by soldering.
And I am currently working on the assembly as described in the wiki.

So, two questions have come up.
One, do I need parts to connect the rotary encoder and encoder_shaft (3d parts)? I am thinking it is like a stick that goes through each other's holes.

Two, I can't get the servo motor and motor_gear(3d parts) to connect properly.

I am looking at the cad model to assemble it, but I couldn't figure it out.

I am sorry for your time, but I would appreciate it if you could help me.

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

rezeck, 2022-10-09:
Hi @Suptree,

It's nice to hear about your progress in developing the robot.

The shaft we use to connect the pinion gear to the encoder is an aluminum rivet.
We only need the mandrel part which should be around 1.80mm in diameter to fit into the encoder.
image.png

The following steps should help your students on these two points:
1) A shaft for the rotary encoder + pinion gear
2) A way to couple the motor gear onto the servo shaft.

Steps:
1) A shaft for the rotary encoder + pinion gear
a) Remove the shank:
image.png
image.png
b) Mandrel diameter should be around 1.80mm to fit into the encoder.
image.png
image.png
c) Cut the dented part with pliers, leaving only the smooth part of the mandrel.
image.png
d) Cut the rest in half. We are going to build two encoder shafts.
image.png
e) Remove imperfections from the cut. The base should be as flat as possible.
image.png
f) Use a hammer to insert the shaft into the pinion gear.
image.png
g) Make the shaft at least 9mm.
image.png
h) Remove artifacts in the pinion gear and make it as clean as possible.
image.png
i) Usually encoders have a metal clip that gives the feeling of wheel steps on the mouse. Use a spatula to knead and flatten this clip.
image.png
image.png
j) Connect the pinion gear to the encoder and check that it rotates as smoothly as possible.
image.png
k) Result after mounting the pinion gear and the encoder.
image.png
image.png
Tip1: to lubricate the transmission between the printed gears, we use graphite lubricant mixed with lubricating oil.
Do not use too much to avoid the risk of falling into electrical components.

Tip2: After fitting the wheel, check by turning it so that the entire transmission runs as smoothly as possible.
The wheel cannot be stuck. In this case, check the gear teeth and sand the imperfections.
It may also be necessary to sand the base of the pinion gear so that it does not rub against the wheel.
This part is kind of boring, but it's crucial for the robot's control and odometry to work.

2) A way to couple the motor gear onto the servo shaft.
a) After modifying the servo motor for continuous rotation. Use the horn that comes with the servo kit to fit the motor gear.image.png
b) Cut the horn leaving only the cylindrical connector.
image.png
c) Trim the cylindrical connector evenly until it fits into the motor gear.
image.png
d) Use super glue to prevent the connector from coming out of the motor gear.
image.png
e) Cut around 1.00-1.20mm from the motor shaft so that the motor gear is as close as possible.
Make it as flat as possible. Trim the shaft if necessary.
image.png
f) Connect the gear motor to the motor shaft using the screw that comes with the servo kit.
image.png
g) Try connecting the servo to the board and let it work.
image.png
h) The idea is to check/test that the gear motor fits well.
It can't be too tight or too loose. It should also rotate as smoothly as possible so that the gear teeth pull the wheel correctly.
In this step, you can connect the wheel and see if the movement is fine.
image.png

Closed 2023-01-06.

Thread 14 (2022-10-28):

Compile-time Error: "i2s.h: No such file or directory"

abrahamjsimpson, 2022-10-28:
I am working on a team that is using HeRo for a research project. We followed your steps [here](https://verlab.github.io/hero_common/firmware/) for installing and setting up Arduino and flashing the firmware to the onboard ESP8266. However, when we went to Verify/Compile it in the Arduino IDE we encountered the following error (note that I am abbreviating the full filepath with ". . ." for brevity):
`In file included from C:\Users\. . .\HeRo\hero_common\hero_firmware\libraries\NeoPixelBus_by_Makuna\src/NeoPixelBus.h:67,
                 from C:\Users\Matthew\Documents\A_School\Capstone\Code\repos\HeRo\hero_common\hero_firmware\firmware\LEDStatus.h:34,
                 from C:\Users\. . .\HeRo\hero_common\hero_firmware\firmware\firmware.ino:37:
C:\Users\. . .\HeRo\hero_common\hero_firmware\libraries\NeoPixelBus_by_Makuna\src/internal/NeoEsp8266DmaMethod.h:42:10: fatal error: i2s.h: No such file or directory
   42 | #include "i2s.h"
      |          ^~~~~~~
compilation terminated.
exit status 1
Error compiling for board NodeMCU 1.0 (ESP-12E Module).
`
The problem seems to be that this file is looking for a header file called "i2s.h", which is not present in the project. However, there _is_ in the same directory a "Esp32_i2s.h" and a corresponding .cpp file. Changing line 42 in NeoEsp8266DmaMethod.h to instead import this file allows it to compile, but we are worried about this causing deeper problems later since HeRo uses the ESP8266, **not** the ESP32 (and indeed, although the code compiles, when uploaded the ESP8266 it does not work as intended, which may become the subject of another Issue on this page if this does not end up being the problem).
In the latest commit of Makuna's NeoPixelBus, NeoEsp8266DmaMethod.h does not import either of these files (or any of the 11 headers that the version in HeRo's repo does). Do you know that the specific version of NeoPixelBus that is currently in the HeRo repo is needed, or should we be using the latest version?

rezeck, 2023-01-07:
Hi @abrahamjsimpson,

Sorry for the late reply! I hope I've been able to find a solution.

After a while, I was able to replicate this error.
I was using version 2.5.0 of the esp8266 board, and this error did not come out.
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

By upgrading the esp8266 board to version 3.1.0, I was able to replicate the error.
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

The solution was to update the NeoPixelBus library as you suggested simply. I was using NeoPixelBus version 2.5.0, which is compatible with esp8266 board 2.5.0.

I've updated the hero repository with the latest version of NeoPixelBus, version 2.7.1, which works with the esp8266 board version 3.1.0.

Please let me know if it now works for you.
Best,
Rezeck

abrahamjsimpson, 2023-01-24:
Hi @rezeck
sorry for _my_ late reply. It does now compile using version 3.1.0 and works! Thank you for your help!

Closed 2023-01-24.

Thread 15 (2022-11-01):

WheelEncoder.h causing reset on ESP8266

willgraham345, 2022-11-01:
My team and I have debugged the firmware on the 2.6 board down to the include statement on WheelEncoder.h. Here is the error we are getting if that helps:
```
ets Jan  8 2013,rst cause:2, boot mode:(3,6)

load 0x4010f000, len 3460, room 16
tail 4
chksum 0xcc
load 0x3fff20b8, len 40, room 4
tail 4
chksum 0xc9
csum 0xc9
v000476d0
~ld

```
we know that the ESP is getting enough power ~4.9V. We assume that the issue stems from within the file where these lines are included:

```#include <hero_common/Encoder.h>

#include <Encoder.h>                    /* https://github.com/PaulStoffregen/Encoder */
#include <SimpleKalmanFilter.h>         /* https://github.com/denyssene/SimpleKalmanFilter */
```

We know that the bots aren't the issue because we are able to flash all of the sketches in the firmware/examples directory, as well as the demos that are included with the ESP including turning the bot into a wifi access point.

could this be an issue with the library location? Any help is extremely appreciated!

***EDIT***
By going into the Encoder.h file supplied by Paul Stoffregen and adding ICACHE_RAM_ATTR to all static void ISR lines
i.e
```
static void sr34(void) { update(interruptArgs[34]); }
----->
static void ICACHE_RAM_ATTR isr34(void) { update(interruptArgs[34]); }
```
the robot now has two red blinking LEDs when we turn it on and covering IR sensors for setup mode does not work.

***EDIT 2.0***
Changing the default mode for the robot in the firmware.ino to
```
config_mode = 1;
```
we are able to get the robot into config mode on startup.

rezeck, 2023-01-07:
Hi @willgraham345,

Sorry for the late reply! After a while, I was able to replicate this error.

I was using version 2.5.0 of the esp8266 board, and this error did not come out.
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

But when I upgrade it to version 3.1.0 and compile it again, when I check the serial output, I get the same error.
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

In fact, the solution was just to update the Encoder library to the most current version (1.4.1 -> 1.4.3). It could have been some internal modification in the esp8266 board that changed the way to implement interrupts, making the Encoder lib need updating.

I tested it here, and everything should work fine since that last commit in the hero repository.

Regarding the configuration mode, it could be some problems with the IR sensor readings. The idea we use as a switch is if all IR readings are greater than ```TOUCH_THRESHOLD```, then the robot should go into configuration mode (blinking pink light). Otherwise, it enters the ROS communication mode. Red blink light (searching for an access point). When connecting to the access point, the light blinks blue and stops. At that moment, it is already possible to connect with the robot by executing the launch file, ```hero_bringup.launch```.

```
/* firmware.ino */
/* Cover all the range sensor to enable web config mode */
  config_mode = rangeSensor.configModeCheck();
  /* Clean status led */
  ledStatus.reset();
  if (config_mode) {
    /* Create an AP that enables the user to setup some parameter of the robot. See config_via_wifi.h. */
    webConfig.init(ledStatus);
  }
  else {
    /* Setup ROS Communication */
```

Please let me know if you were able to fix these both issues.
Best,
Rezeck

Closed 2023-09-05.

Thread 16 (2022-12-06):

Materials: Bultin Battery Charger Resistors

hauff, 2022-12-06:
Hello, I have a question regarding the assembly materials [hero_resources/assembly_materials.pdf](https://github.com/verlab/hero_common/blob/7be0daf3eff30f7db28b033778bef5dd4830c5d5/hero_resources/assembly_materials.pdf).

There are 3 resistors (`R12`, `R13`, `R14`) listed in the section `Bultin Battery Charger`.
Are the descriptions (1K Ohm, 100 Ohm, 120 Ohm) correct?
I am asking because I thought the code 103 for example means 10 kOhm? (and 102 := 1 kOhm, 122 := 1.2 kOhm)

| Part Name | Device | Description |
|---|---|---|
| R12 | Resistor 103 | SMD Resistor 1K Ohm |
| R13 | Resistor 102 | SMD Resistor 100 Ohm |
| R14 | Resistor 122 | SMD Resistor 120 Ohm |

rezeck, 2023-01-05:
Hi, @hauff,

You are absolutely right! Thanks for pointing this one out.
I have already updated the website and document with this information.
The correct is:
Part Name | Device | Description
-- | -- | --
R12 | Resistor 102 | SMD Resistor 1K Ohm
R13 | Resistor 101 | SMD Resistor 100 Ohm
R14 | Resistor 121 | SMD Resistor 120 Ohm

I have also checked all the other descriptions, and they seem correct. If you find another issue, please let me know.
Regards,
Rezeck

hauff, 2023-01-05:
Hi @rezeck,

Thank you for answering my question. 🙂

Closed 2023-01-05.

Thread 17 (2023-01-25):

Reading the IR Sensor Data

jacobh2299, 2023-01-25:
Hello! I am working with a research lab that has manufactured 5 of your Hero 2.6 robots. We seem to have run into a few issues when it comes to running the example code that you have provided in your github. While trying to run the random.launch python script, our robot only rotates clock-wise. I have a few screenshots of the rostopic laser that was provided of our IRs while uncovered and while covered. Our understanding is that the IRs should be defaulted to 0.5, but it appears that they are not defaulting to that very well. The first image is of the IRs uncovered, while the second image is of the IRs covered.
If you could help us understand what we are looking at in the laser rostopic or help explain the random.launch script that you had written I think it would help our debugging process run a bit quicker:

Uncovered IRs:
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

Covered IRs:
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

Note that we changed the python script for random.launch to use python3 as we were getting errors regarding Yaml while only using Python 2.x. Changing to python3 resolved the crash issue, but the bot still only rotates clock-wise while running the script.

Thanks!
University of Utah Research Team

rezeck, 2023-02-13:
Hey @jacobh2299,

Sorry again for the late reply.

It seems to me that the laser is not working properly. In the second figure,  the ranges field should be a value close to range_min. The ranges field contains the distance (in meters) for 16 IR sensors. We interpolate these 16 IR sensors (blue) from the 8 real IR sensors (red) on the robot. The field intensities are the light intensity (0-1023) received by the photodiode minus the ambient light intensity. That is, it would be the intensity of light returned after reflecting on an object. The correspondence IR sensor and the position in the robot are given in the following.
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

This is a video of expected behavior.

https://user-images.githubusercontent.com/14208261/218348064-9638f3d9-a66f-43f9-814f-426c5cd91aa5.mp4

*In your case, it may be a problem due to a lack of calibration or hardware failure. Please, test the two procedures below and let me know if they worked for you.*

**Calibration**
To calibrate the 8 IR sensors, use the launch file ```hero_confmode.launch```, and the ros service ```/hero_*/ir_calibration```.
The process of calibration is done as follows:

1) place an object (preferably white color) at a known distance (d) from one of the IR sensors you want to calibrate;
2) Use the laser topic ```rostopic echo \hero_*\laser``` to see the intensity for that sensor;
3) The calibration parameter is obtained by the equation (intensity) * d^2.
4) Repeat this procedure for all sensors and save these 8 values;
5) With the 8 calibration values in hand, run the calibration service:
```sh
rosservice call /hero_*/ir_calibration "{IR0: 0.39, IR1: 0.28, IR2: 0.45, IR3: 0.29, IR4: 0.52, IR5: 0.22, IR6: 0.23, IR7: 0.28}"
```

I am still improving this process and the following is an alternative.
You must place 8 objects at the same distance from the 8 IR sensors.
I used the #D printer to make [support](https://github.com/verlab/hero_common/tree/noetic-devel/hero_resources/3d_parts/ir_calibration) to help with this setup.
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

After placing the objects, run the script:
```sh
rosrun hero_examples hero_ir_calib.py hero_*
```
This is a video showing how to execute this script.

https://user-images.githubusercontent.com/14208261/218351257-2bc2767a-8aff-4ed9-b512-e373bce10820.mp4

**IR Sensor Test**
If you still don't have any luck, proceed with this process to see if everything is ok with the hardware. Try burning the RangeSensor firmware, and check the output for consistency. Maybe it has an IR sensor soldered upside down.
This is a video showing how to proceed with this test.

https://user-images.githubusercontent.com/14208261/218352369-a99e7c69-c070-4dcd-ba82-57c5e348644f.mp4

Please let me know if everything works out.
I'm still trying to refine and automate this sensor and actuator calibration step.
As soon as I finish this, I will update the tutorial.

Best,
Rezeck

jacobh2299, 2023-02-17:
Thank you for such a detailed reply! I found your commits in the noetic-devel branch and downloaded the new hero_ir_calib.py file. It seems to be running properly on our end, but our values displayed from rostopic laser still appear to not be calibrated (likely because we do not have well measured distances when calibrating). I am currently 3D printing the part you made to assist in calibration and will update this post when completed.

Thanks again
Jacob, University of Utah Drew Research Lab (DRL) Swarm Robotics

rezeck, 2023-02-22:
Hey @jacobh2299 ,

Yes, the IR positions between version 2.5 and >= 2.6 are different. This is because there is a design error in board version 2.5. To (temporally) fix it, I have to flip the TCRT5000 and also the IR and phototransistor inside the plastic case. Anyway, I definitely suggest NOT using version 2.5. I will put this warning in the tutorial.

Since you are using board version 2.6, this problem has been fixed. So I think the way you placed the TCRT5000 (as shown in your figure) is correct.

When soldering the TCRT flipped in version 2.6, it may probably burn the IR. You can check the IR using the cellphone camera (with no IR filter) or a webcam. It should blink a purple light. To test the phototransistor, try putting the multimeter (DC voltage 0-5V) as in the figure.
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

Cover and uncover the phototransistor. If the voltage consistently changes, it should work fine. Anyway, if you have another TCRT5000, try to replace one of them and test it.

Let me know if you find something or if you have more questions.

Best,
Rezeck

Albulinek, 2024-10-01:
@rezeck

The testing firmware on 2.7 showcased in your video is from branch "melodic-devel"

I am not sure if there was some mixup of files for "master" and "noetic-devel", but testing RangeSensor firmware in those branches does not produce any readable values from python script.

I was searching topics here after failing to bring up Hero to WiFi hotspot mode. I will also check original firmware itself. I had to comment out config check part and hardcode Hero bringup to configure it properly.

Lastly, the material assemby was missing some crucial parts, along with wiki is missing details about PCB assembly. I am not sure if this is intentional, but once I am done polishing Hero on my side, I will try to open PR to help others with building their own bot.

Thanks for providing us with this awesome resource!

Closed 2024-02-15.

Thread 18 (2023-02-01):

Rosservice List not displaying expected results

jacobh2299, 2023-02-01:
Hello again! Another question for you. We are not getting an expected rosservice list as shown in your instructions website. We expect to see several services that you have included such as pid_calibration, set_frequency, set_odom, and set_pid_parameters, but we are only receiving
/rosout/get_loggers
/rosout/set_logger_level
/rosserial_server/get_loggers
/rosserial_server/set_logger_level

Here is a screenshot of our computer connected to a robot, the rostopic list, and the rosservice list:

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

Here is also a screenshot of our catkin_make return terminal:

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

We have tried re-flashing the firmware on the robots with the ESP version 2.5 such as you recommended before, but with the current version of firmware, using the latest version of the board has been working. We also tried re-cloning the repo to a different computer running Ubuntu and the service list was still not showing. I would also like to note that we did not use the Docker Method but rather built from source, although I don't think that this is a problem.

Best,
University of Utah Robotics Team

rezeck, 2023-02-09:
Hey @jacobh2299,

Sorry for the late reply.

Lately, it has been hard to commit myself to develop the robot's tutorial, but whenever I get some time, I complete and improve it.

About the issue above, the problem is with the rosserial package. The official version has two implementations: one in Python and another in C++.

The C++ version implements communication only via topics but supports multiple robots. The Python version implements communication via topics and services but does not support multiple robots.

A while ago, I was trying to debug and add communication via services in the C++ version of rosserial. You can find some modification that may worked for a while, but mostly I find stopped working ([Issue](https://github.com/ros-drivers/rosserial/pull/453)).

As an option, I decide to leave the robot services only for configuration. Since then, two launch files have been able to bring up the robots: ```hero_bringup.launch``` and ```hero_confmode.launch```.

The first runs the C++ version of rosserial and works for multiple robots. The second runs the Python version and enables communication via the service.

So, I assume you ran ```hero_bringup.launch``` instead of ```hero_confmode.launch```. Can you confirm this?

Best,
Rezeck

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

jacobh2299, 2023-02-10:
I can confirm this! I was using the hero_bringup.launch, thank you for the explanation! We have sense used the hero_confmode.launch, and with some light edits to the common.xacro file we were able to get all the services running. I will link our edits to common.xacro here.

The main reason we are looking into the services was because you have a service listed as IR_Calibration, and we seem to be experiencing many issues regarding the IRs. Hopefully with more experimentation on the values we receive from the IRs we will be able to run the random.launch file to run properly. If you could tell us what the IR_calibration service does and how it should effect the values that we receive from the IRs, that would really help streamline our debugging process. Thanks!

Edits to common.xacro:

```
<?xml version="1.0"?>
<robot xmlns:xacro="http://www.ros.org/wiki/xacro">

  <!-- Some properties of HERO -->
  <xacro:property name="PI" value="3.1415926535897931" />
  <xacro:property name="wheel_separation" value="0.06460" />
  <!-- <property name="wheel_diameter" value="0.0496" /> -->
  <xacro:property name="wheel_diameter" value="0.050" />

  <xacro:macro name="cylinder_inertia" params="m r h">
    <inertia ixx="${m*(3*r*r+h*h)/12}" ixy = "0" ixz = "0" iyy="${m*(3*r*r+h*h)/12}" iyz = "0" izz="${m*r*r/2}" />
  </xacro:macro>

  <xacro:macro name="box_inertia" params="m x y z">
    <inertia ixx="${m*(y*y+z*z)/12}" ixy = "0" ixz = "0" iyy="${m*(x*x+z*z)/12}" iyz = "0" izz="${m*(x*x+z*z)/12}" />
  </xacro:macro>

</robot>

```

rezeck, 2023-02-13:
Hey @jacobh2299

Excellent!

Sure, I just replied to your issue #17.
Let me know if this may help you guys with the IR sensors problem.
Then check if the random walk algorithm works.

Thanks for reporting this issue.

Best,
Rezeck

Closed 2023-02-17.

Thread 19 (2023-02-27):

Battery Connector Polarity is Labeled Incorrectly on PCB

abrahamjsimpson, 2023-02-27:
We are using version 2.6. Looking at the PCB design (board.brd), I noticed that between the connector where the battery is plugged in and the header for the left encoder there is silkscreen text (on layer 25, tNames) that says "VCC GND" (see screenshot).
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
It seems that this label is intended for the battery connector; however, if so, they are reversed! As the screenshot shows, ground is actually on the _left_ and VCC is on the _right_. This should be fixed.

rezeck, 2023-03-06:
Hey @abrahamjsimpson,

Thank you for reporting this issue.

I incorporated this modification in the 2.7 version of the board.

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

Best,
Rezeck

abrahamjsimpson, 2023-03-20:
Thank you!

Closed 2023-03-20.

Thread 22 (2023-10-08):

Short circuits (Vin/VCC and GND; MUX_X7 and GND) in latest PCB design (v2.7 2023-03-05)

Honza0297, 2023-10-08:
In the latest version of the PCB (v2.7, 2023-03-05), there is a short circuit between VCC (specifically VCC pin of capacitor C1) and GND (specifically GND pins of 4051) via B+ route (highlighted in the image). In fact, the whole B+ route seems misplaced, crossing several other routes in the same layer. Please correct me if I am wrong.

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

The issue is present in the real PCB as well. Actually, another issue is present in the physical PCB: route MUX_X7 is shorted to GND (GND pin of capacitor C1). The position itself of of the C1 capacitor seems unfortunate, colliding with Neopixel LED as well.

rezeck, 2023-10-08:
Hi @Honza0297

Thank you for bringing this critical issue to our attention. I sincerely apologize for any inconvenience this may have caused. It appears there may have been an error during the upload of updates for version 2.7. This layout is not supposed to be of the PCB version 2.7.

# Version 2.7 (2023.10)
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

Gerber: [board_2023-10-08.zip](https://github.com/verlab/hero_common/files/12841293/board_2023-10-08.zip)

I have now uploaded the corrected files for version 2.7, and after careful review, I did not identify any further issues.
Your feedback is invaluable, and if you have any additional suggestions or improvements for the PCB layout, please feel free to submit a pull request. We greatly appreciate your contribution.

Once again, I apologize for any problem this may have caused, and I appreciate your understanding.

Best regards,
Rezeck

Honza0297, 2023-10-08:
Wow, thank you for the fast fix, @rezeck! I sent the fixed version to production and once the new PCBs arrive, I'll let you know whether everything works.

rezeck, 2023-10-08:
Thanks!! =)

Honza0297, 2023-11-15:
I finally managed to test everything and PCB seems working flawlessly. :)

However, I have run into another issue. When I upload the firmware and try to teleoperate the robot with:

```
roslaunch hero_bringup hero_bringup.launch
roslaunch hero_bringup hero_teleop.launch id:=0
```

the robot behaves pretty chaotically, both in real life and rviz. TFs are moving according to real movement etc., but when I command it to go straight, it just chaotically moves around. Am I supposed to tune some parameters? Thanks in advance!

rezeck, 2023-11-16:
Hi @Honza0297 ,

Thank you for your reply. It's great that PCB is working now.

Yes! I do not know if you pass through the calibration step [here](https://verlab.github.io/hero_common/calibration/). If not, try calibrating the motor's PWM endzone and the PID parameters for both the position and velocity controller. You should set the PWM endzone with the values that fully stop your motors (theoretically 1500). The PID params you can use the ones in the tutorial, as they should be reasonable to start using.
> PS.: Use this bringup ```roslaunch hero_bringup hero_confmode.launch``` instead.

Also, when you are prompted to command the robot using hero_teleop, try to decrease the linear speed to ~0.1 m/s. Maximum is 0.20 m/s.

If the robot is turning around when you command it forward (keyboard ```I```), you may check these points:
- Motor calibration and PWM parameters?
- Is the encoder speed filter working properly (Tip: use rqt to plot them)?

Please let me know if you manage it to work.

> PS: To calibrate the IR sensors, follow this [issue](https://github.com/verlab/hero_common/issues/17). I could not find time to add this information to [webpage tutorial](https://verlab.github.io/hero_common/).

Closed 2024-02-15.

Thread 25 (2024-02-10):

can i replace CD4051BM

buddytex, 2024-02-10:
can i replace CD4051BM without another mux, if so how to determine please help

rezeck, 2024-02-15:
Hi @buddytex

The CD4051BM can be operated on a wide range of supply voltages, anywhere between 3V and 20V (we are using 5V supply). Another alternative is 74HC4051, which only operates from a 5V supply. To determine if it is compatible, you just have to check the package (SOIC-16), supply voltage (5V), and the pinout to see if it matches with the CD4051BM. Otherwise, you have to modify the PCB routing traces.

buddytex, 2024-02-24:
I dont know where to the place charging module and step up module, I cant find the resources or images to place it

rezeck, 2024-03-02:
Hi @buddytex ,

Apologies for the delay in responding. I've been juggling multiple tasks lately, making it challenging to allocate time to complete the HeRo tutorial.

Regarding your query about the step-up module, I recommend referring to the details provided in issue #12. Hopefully, it sheds some light on the placement of the step-up module onto the board.

As for the charging module (TP4056), it's soldered directly onto the board. I've attached an image below illustrating where the components should be placed for your reference.

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

Feel free to reach out if you need further help or clarification on any aspect of the project.

Best regards,
Rezeck

Closed 2024-04-01.

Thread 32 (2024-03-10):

Placing charging module

buddytex, 2024-03-10:
I'm unsure about the placement of the TP4056 charging module. The assembly materials include a SOP 8 version of the TP4056 so I'm unsure if the module is necessary. I noticed the marking 'B+' on the PCB, which suggests a connection point for the module. However, when I try to place the charging module, it seems awkward and out of place.
 I'm eagerly awaiting your guidance on where to position the module.

rezeck, 2024-03-10:
Hi @buddytex,

Thank you for reaching out with your concern regarding the placement of the TP4056 charging module. Allow me to provide clarification on this matter.

In the current iteration of the board, specifically version 2.5 and later, we have integrated a TP4056 charging circuit directly onto the PCB. Consequently, the separate TP4056 module included in the assembly materials is no longer necessary. I understand your confusion regarding the 'B+' marking on the PCB, which indeed indicates the battery-positive connection point. However, this marking is intended for guiding the connection of the step-up (MT3608) module, rather than the TP4056.

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

To offer further assistance, I've attached some images showcasing the board in its current version I have here (v2.5). You'll notice that in this version, a direct connection between the MT3608 and the board may require some wiring. However, in subsequent versions the alignment should be seamless, and you can utilize header pins for a secure connection.

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

I hope this clears up any confusion, and please don't hesitate to ask if you need further assistance. We're here to help!

Best regards,
Rezeck

Closed 2024-04-01.

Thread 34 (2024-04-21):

PID Controller Issue

Khaled3ly, 2024-04-21:
Hello @rezeck,

I can't understand how does the PID controller work as the input signal is velocity (cm/s) and encoder reading is also velocity (cm/s) while the output is PWM.... is there a transfer function that takes output (cm/s) and transfers it to PWM ?

Thanks in advance.

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

varunraveendra, 2024-06-30:
Hi @Khaled3ly ,
I have been working on Hero robots for a while now. Talking about the PID controller, I believe that it takes in the desired and the current velocity and outputs adjusted velocity. This is then summed with the MotorDeadZone value. If you are looking at raw values of the adjusted velocity, then you might notice that it can go up to +250 or -250. The code below  under VelocityControl.ino might give you a better explanation:
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

I hope this helps.

-Varun Raveendra

rezeck, 2025-09-27:
Hi @Khaled3ly, we control PWM by closing a velocity loop: the encoder measures wheel speed, the PID compares it to the target speed, and its output is treated as the actuator effort command that the driver maps directly to PWM duty. Here the PID already returns a bounded value in the driver’s units, we add a small dead-zone offset to overcome static friction, and send that to the motor driver—no extra transfer block is needed, just tuning (PI first, with saturation/anti-windup). If this clarifies it, I can close the issue.

thanks @varunraveendra

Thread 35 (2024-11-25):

3D model construction - LiPo fire hazard

neaxi, 2024-11-25:
Hello

Upon inspection of the model, are you seriously suggesting to drive screws through the Lithium accumulator?!
Here's screenshot from the provided Fusion file clearly showing screws are going INTO the battery by design.
The assembly guide states these are _"M2.5x10mm Screws Self-Tapping"_. They have a sharp tip and no problem poking a hole into the battery.
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

The hazards of damaging LiPo batteries are well documented, ranging from release of the internal chemicals to worst case resulting into combustion and fire.
**The current design is definitelly not safe!**

Also, there is no barrier between the screws of the wheels and the battery. There's 1.6mm tolerance, se plenty of room to add extra 2 perimeters for safety.

rezeck, 2024-11-27:
Hello @neaxi

Thank you very much for your interest and for reporting this critical issue.

Upon review, I believe there might indeed be a flaw in the design regarding the screw and battery dimensions. The screw size appears to be slightly over 10mm when considering the screw head, and the battery model used is larger than the one specified in the BOM. Your concern is entirely valid, as this discrepancy could lead users to inadvertently use non-specified materials during assembly, potentially resulting in dangerous situations.

I deeply appreciate you bringing this to our attention. If you have any suggestions on how to adapt the design or introduce a physical barrier in the CAD model to mitigate this risk, I would be thrilled to review a pull request or any contributions.

**For now, as a safety measure, I will add a note in the assembly process documentation to alert users to this risk.**
Thank you again for your feedback!

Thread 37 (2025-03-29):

Servo

buddytex, 2025-03-29:
How is the sg 90 supposed to move the wheel continuosly

rezeck, 2025-09-27:
Hi @buddytex,

Thank you for your inquiry regarding SG90 servos capable of continuous rotation.

You have a couple of options:

## Purchase Pre-Modified Servos
Many hobby electronics suppliers offer SG90 servos that have already been modified for continuous rotation, which can be a convenient plug-and-play solution.

## Manual Adaptation
If you prefer to adapt a standard SG90 servo, the following video provides an excellent guide:

Video: [SERVO CONTINUOUS ROTATION MOD WITH PWM ROTATION/SPEED CONTROL](https://www.youtube.com/watch?v=4Z-j6bUJTQ8)
Channel: H.R.E SYSTEMS

This tutorial demonstrates how to modify an SG90 (or similar mechanical servo) to achieve continuous rotation with PWM control over speed and direction. Key steps covered in the video include:

1. Removing the Potentiometer's Physical Stop
3. Reassembling and Calibrating the Servo's Neutral Point
5. Securing the Potentiometer to maintain the calibration
7. Final Testing to ensure correct continuous operation
9. I hope this information is helpful for your project!

Best regards, Rezeck

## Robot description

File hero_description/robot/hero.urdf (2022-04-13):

<?xml version="1.0" encoding="utf-8"?>
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
<robot name="hero_0">
  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
  <link name="base_link">
    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
    <inertial>
      <mass value="0.090"/>
      <origin rpy="1.57079632679 0 0" xyz="0 0.0002 0"/>
      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
    </inertial>
  </link>
  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
  <joint name="hat_joint" type="fixed">
    <origin rpy="0 0 0" xyz="-0.00245 -0.00216 0.06027"/>
    <parent link="base_link"/>
    <child link="hat_link"/>
  </joint>
  <link name="hat_link">
    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
    <inertial>
      <mass value="0.010"/>
      <origin rpy="0 0 0" xyz="0 0 0"/>
      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
    </inertial>
  </link>
  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
  <joint name="left_wheel_joint" type="continuous">
    <parent link="base_link"/>
    <child link="left_wheel_link"/>
    <origin rpy="0 0 0" xyz="0.0 0.0323 0.01548"/>
    <axis xyz="0 1 0"/>
    <limit effort="0.1" velocity="0.3"/>
    <dynamics damping="0.0001" friction="0.0"/>
  </joint>
  <link name="left_wheel_link">
    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
    <inertial>
      <mass value="0.020"/>
      <origin rpy="1.57079632679 0 0" xyz="0 0 0"/>
      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
    </inertial>
  </link>
  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
  <joint name="right_wheel_joint" type="continuous">
    <axis xyz="0 1 0"/>
    <limit effort="0.1" velocity="0.3"/>
    <dynamics damping="0.0001" friction="0"/>
    <origin rpy="0 0 0" xyz="0.0 -0.0323 0.01548"/>
    <parent link="base_link"/>
    <child link="right_wheel_link"/>
  </joint>
  <link name="right_wheel_link">
    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
    <inertial>
      <mass value="0.020"/>
      <origin rpy="-1.57079632679 0 0" xyz="0 0 0"/>
      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
    </inertial>
  </link>
  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
  <joint name="laser_joint" type="fixed">
    <axis xyz="0 1 0"/>
    <origin rpy="0 0 0" xyz="0 0 0.051"/>
    <parent link="base_link"/>
    <child link="laser_link"/>
  </joint>
  <link name="laser_link">
    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
    <inertial>
      <mass value="1e-5"/>
      <origin rpy="0 0 0" xyz="0 0 0"/>
      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
    </inertial>
  </link>
  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
</robot>

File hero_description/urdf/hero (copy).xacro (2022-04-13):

<?xml version="1.0"?>
<robot xmlns:xacro="http://www.ros.org/wiki/xacro">

  <!-- Here was the base link definitions -->
  <link name="base_link">
    <visual>
      <origin xyz="0 0 0" rpy="0 0 0" />
      <geometry>
        <mesh filename="package://hero_description/meshes/base_link.dae" scale="1 1 1"/>
      </geometry>
    </visual>
    <collision>
      <origin xyz="0 0 0" rpy="0 0 0" />
      <geometry>
        <!-- <cylinde size="0.068 0.068 0.048"/> -->
        <cylinder length="0.048" radius="0.036"/>
      </geometry>
    </collision>
    <inertial>
      <mass value="0.090" />
      <origin xyz="0 0 0" rpy="0 0 0"/>
      <xacro:cylinder_inertia m="0.090" r="0.035" h="0.055"/>
    </inertial>
  </link>
  <gazebo reference="base_link">
    <gravity>1</gravity>
    <mu1 value="0.01"/>
    <mu2 value="0.01"/>
    <!-- <maxVel value="0.10"/>  -->
    <maxContacts>4</maxContacts>
    <selfCollide>1</selfCollide>
  </gazebo>

  <!--  Here was the hat joint and link -->
  <joint name="hat_joint" type="fixed">
    <origin xyz="0.0001 0 0.038" rpy="0 0 0" />
    <parent link="base_link"/>
    <child link="hat_link"/>
  </joint>
  <link name="hat_link">
    <visual>
      <origin xyz="0 0 0" rpy="0 0 0" />
      <geometry>
        <mesh filename="package://hero_description/meshes/hat.dae" scale="1 1 1"/>
      </geometry>
    </visual>
    <collision>
      <origin xyz="0 0 0" rpy="0 0 0" />
      <geometry>
        <!-- <box size="0.068 0.068 0.02"/> -->
        <cylinder length="0.02" radius="0.040"/>
      </geometry>
    </collision>
    <inertial>
      <mass value="0.010" />
      <origin xyz="0 0 0" rpy="0 0 0"/>
      <!-- <xacro:box_inertia m="0.010" x="0.07" y="0.07" z="0.02"/> -->
      <xacro:cylinder_inertia m="0.010" r="0.035" h="0.02"/>
    </inertial>
  </link>
  <gazebo reference="hat_link">
    <gravity>1</gravity>
    <!-- <mu1 value="0.005"/>
    <mu2 value="0.005"/> -->
    <maxVel value="0.10"/> 
    <maxContacts>0</maxContacts>
    <selfCollide>0</selfCollide>
  </gazebo>

  <!--  Here was the left wheel joint and link -->
  <joint name="left_wheel_joint" type="continuous">
    <parent link="base_link"/>
    <child link="left_wheel_link"/>
    <origin xyz="0 ${wheel_separation/2} 0.0005" rpy="0 0 0" />
    <axis xyz="0 1 0" />
    <limit effort="100" velocity="0.3"/>
    <dynamics damping="0.0" friction="0.0" />
  </joint>
  <link name="left_wheel_link">
    <visual>
      <origin xyz="0 0 0.0" rpy="${PI/2} 0 0" />
      <geometry>
        <mesh filename="package://hero_description/meshes/wheel.dae" scale="1 1 1"/>
      </geometry>
    </visual>
    <collision>
      <origin xyz="0 0 0.0" rpy="${PI/2} 0 0" />
      <geometry>
        <cylinder length="0.008" radius="${wheel_diameter/2.0}"/>
      </geometry>
    </collision>
    <inertial>
      <mass value="0.010" />
      <origin xyz="0 0 0" rpy="${PI/2} 0 0"/>
      <xacro:cylinder_inertia m="0.010" h="0.008" r="${wheel_diameter/2.0}"/>
    </inertial>
  </link>
  <gazebo reference="left_wheel_link">
    <mu1 value="0.8"/>
    <mu2 value="0.8"/>
    <!-- <maxVel value="0.10"/>  -->
    <!-- <kp value="10000000.0"/>
    <kd value="1.0"/>
    <fdir1 value="1 0 0"/> -->
    <gravity>1</gravity>
    <maxContacts>4</maxContacts>
    <selfCollide>0</selfCollide>
  </gazebo>

  <!--  Here was the right wheel joint and link -->
  <joint name="right_wheel_joint" type="continuous">
    <axis xyz="0 1 0" />
    <limit effort="100" velocity="0.3"/>
    <dynamics damping="0.0" friction="0" />
    <origin xyz="0 ${-wheel_separation/2} 0.0005" rpy="0 0 0" />
    <parent link="base_link"/>
    <child link="right_wheel_link"/>
  </joint>
  <link name="right_wheel_link">
    <visual>
      <origin xyz="0 0 0.0" rpy="${-PI/2} 0 0" />
      <geometry>
        <mesh filename="package://hero_description/meshes/wheel.dae" scale="1 1 1"/>
      </geometry>
    </visual>
    <collision>
      <origin xyz="0 0 0.0" rpy="${-PI/2} 0 0" />
      <geometry>
        <cylinder length="0.008" radius="${wheel_diameter/2.0}"/>
      </geometry>
    </collision>
    <inertial>
      <mass value="0.010" />
      <origin xyz="0 0 0" rpy="${-PI/2} 0 0"/>
      <xacro:cylinder_inertia m="0.010" h="0.008" r="${wheel_diameter/2.0}"/>
    </inertial>
  </link>
  <gazebo reference="right_wheel_link">
    <mu1 value="0.8"/>
    <mu2 value="0.8"/>
    <!-- <maxVel value="0.10"/>  -->
    <!-- <kp value="10000000.0"/>
    <kd value="1.0"/>
    <fdir1 value="1 0 0"/> -->
    <gravity>1</gravity>
    <maxContacts>4</maxContacts>
    <selfCollide>0</selfCollide>
  </gazebo>

</robot>

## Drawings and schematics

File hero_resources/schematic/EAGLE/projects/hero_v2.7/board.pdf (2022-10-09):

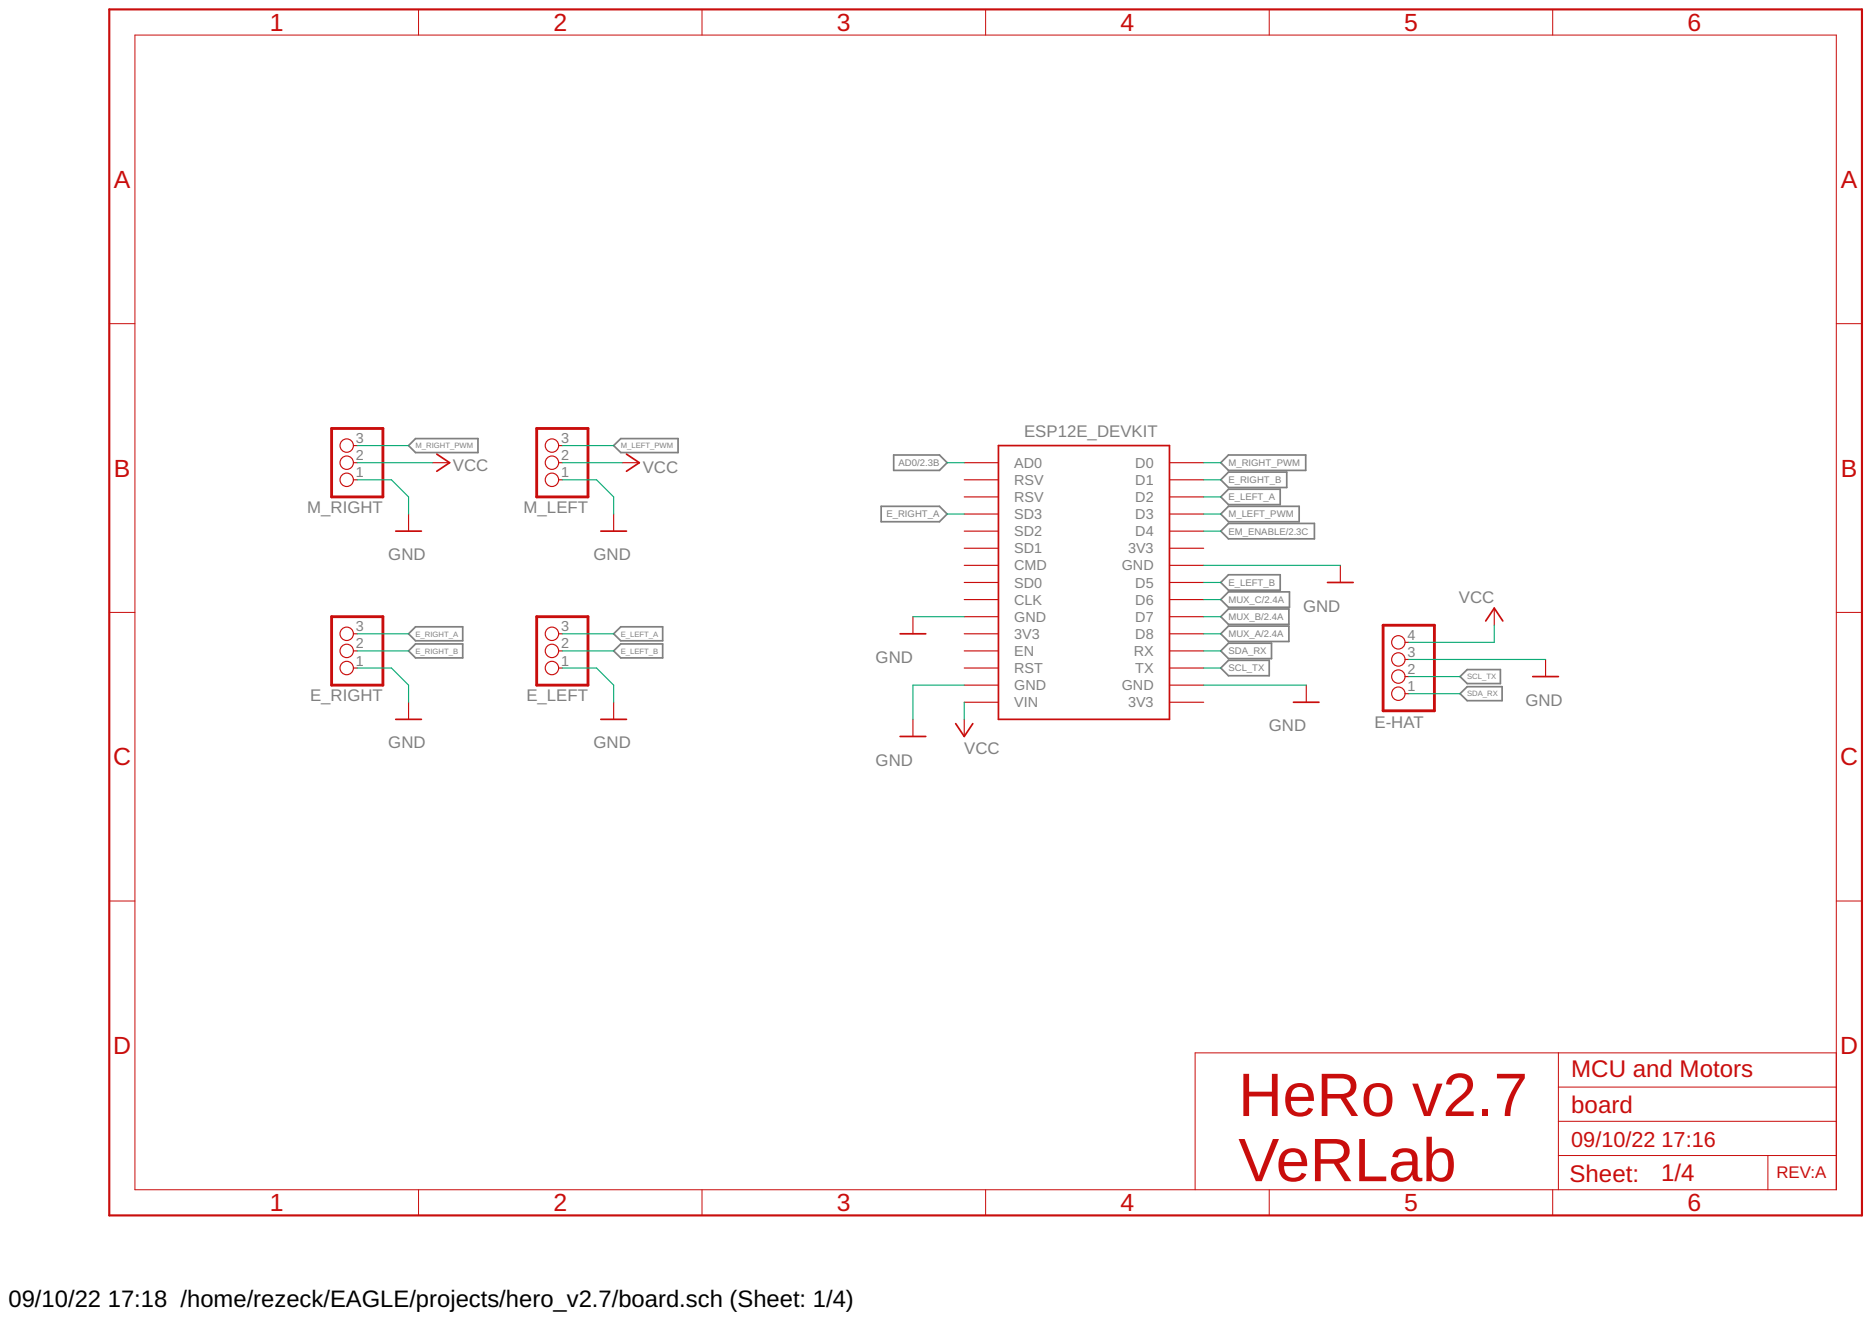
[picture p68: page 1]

09/10/22 17:18 /home/rezeck/EAGLE/projects/hero_v2.7/board.sch (Sheet: 1/4)

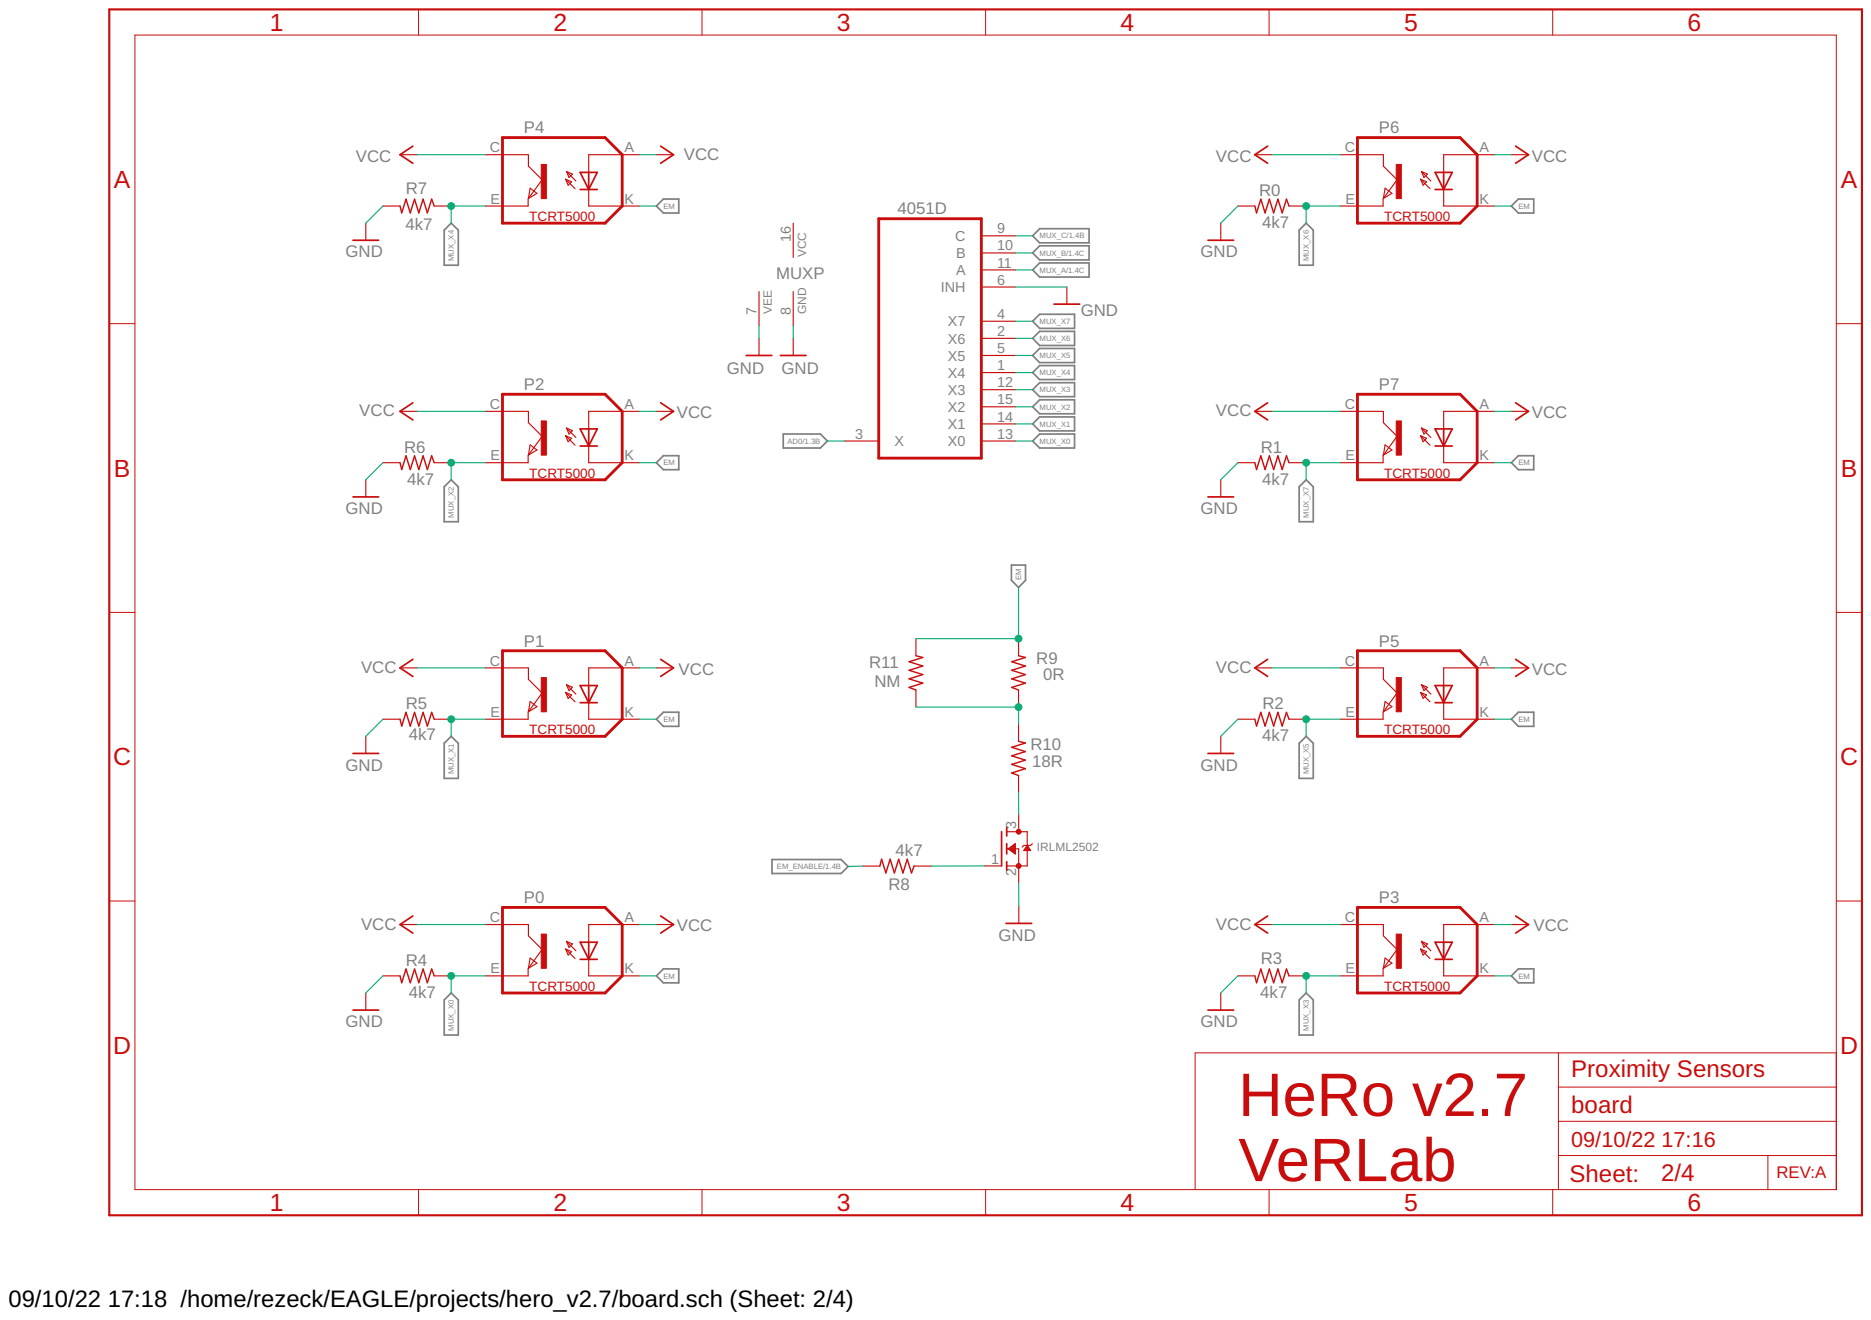
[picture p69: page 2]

09/10/22 17:18 /home/rezeck/EAGLE/projects/hero_v2.7/board.sch (Sheet: 2/4)

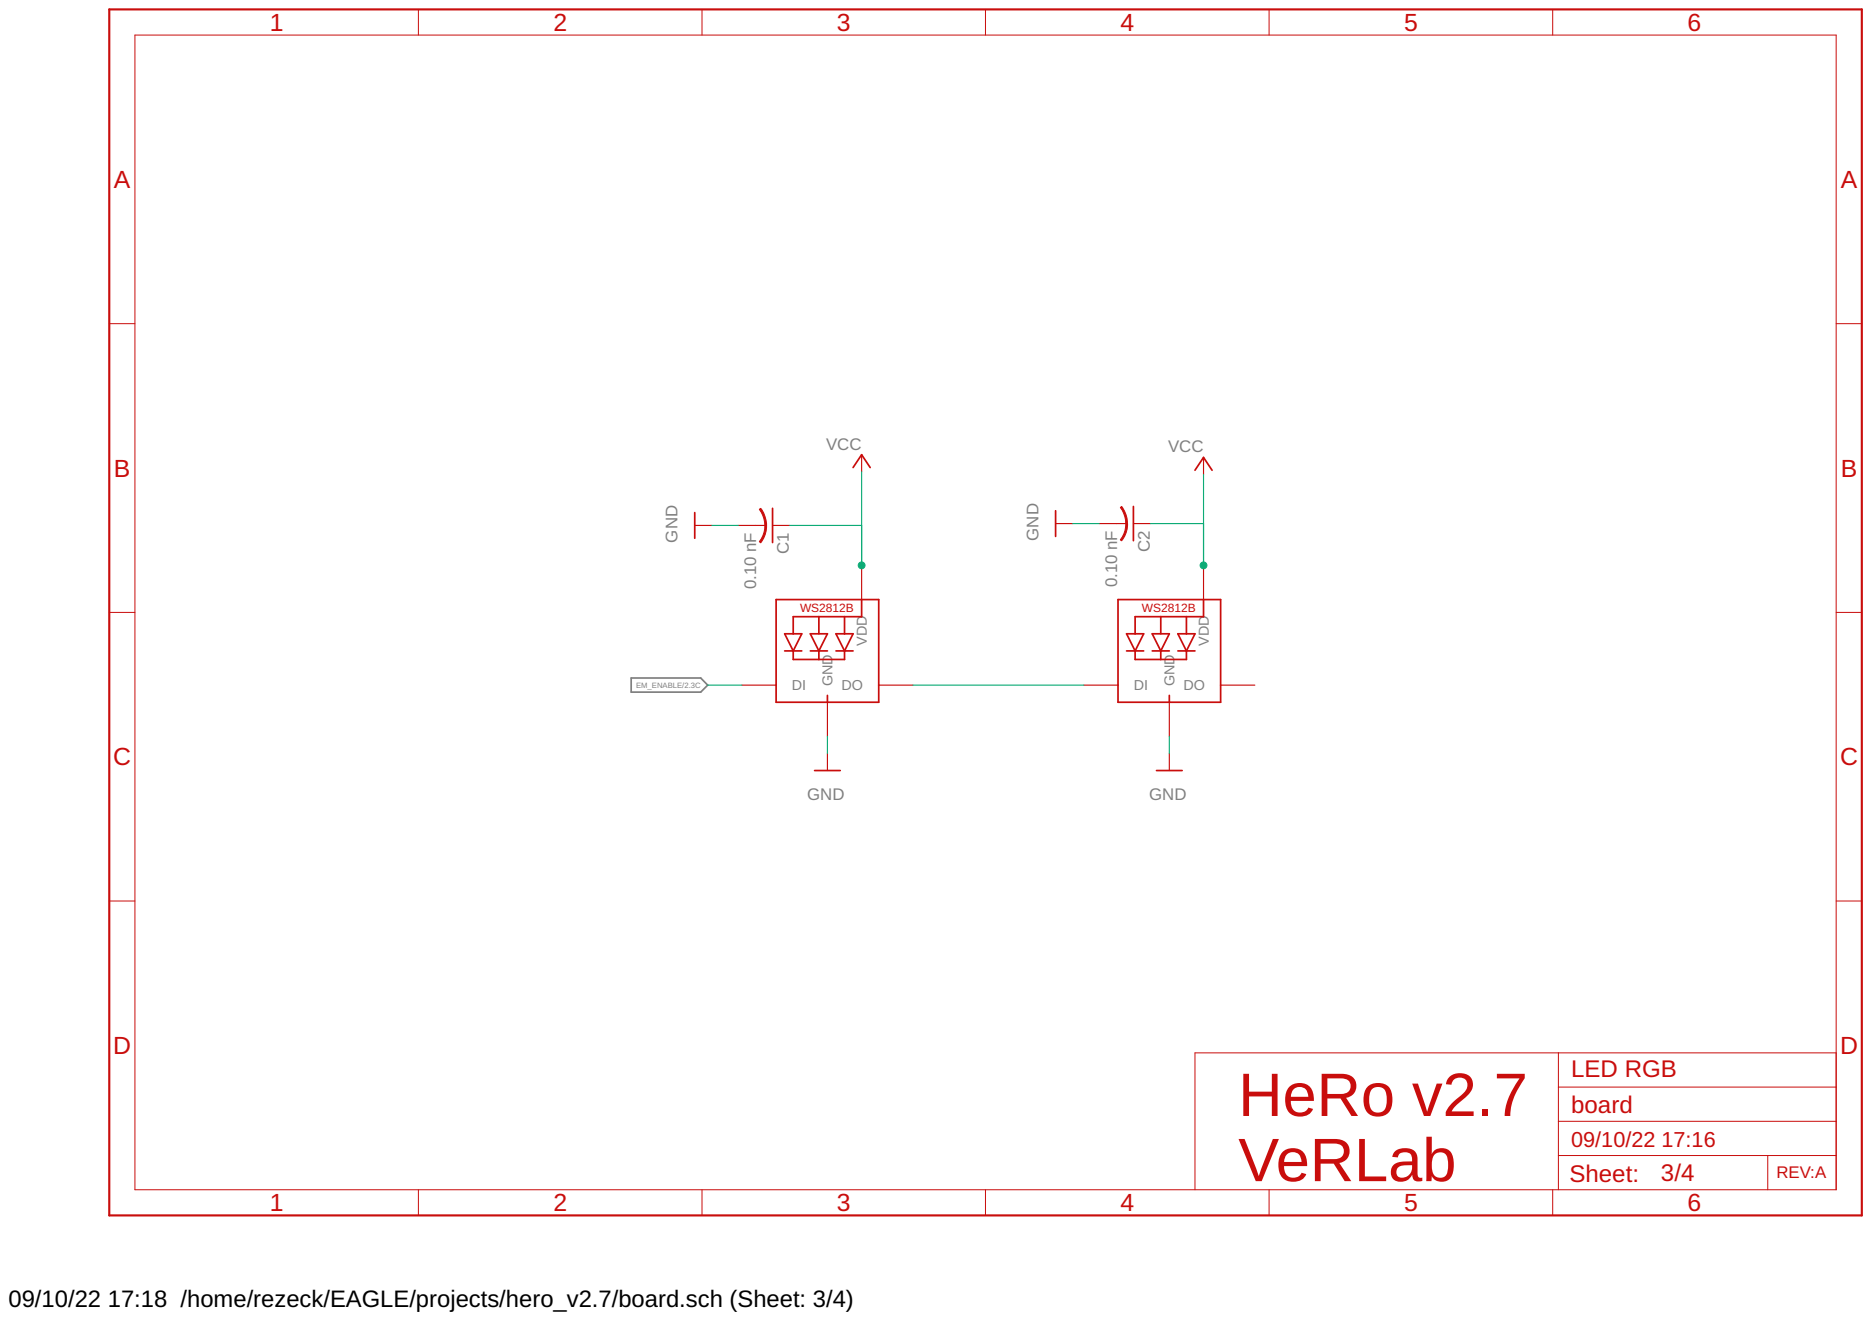
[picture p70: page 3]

09/10/22 17:18 /home/rezeck/EAGLE/projects/hero_v2.7/board.sch (Sheet: 3/4)

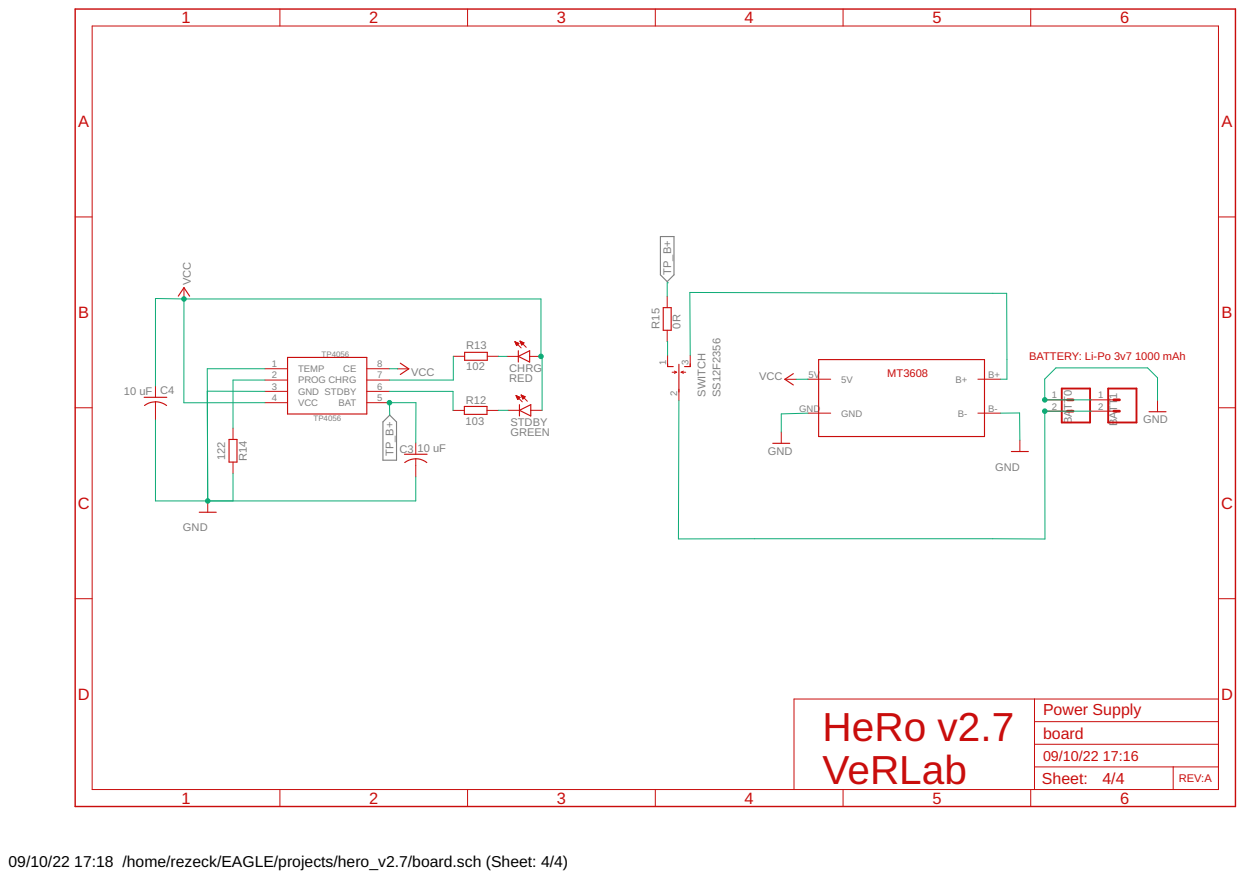
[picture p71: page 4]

BATTERY: Li-Po 3v7 1000 mAh

09/10/22 17:18 /home/rezeck/EAGLE/projects/hero_v2.7/board.sch (Sheet: 4/4)

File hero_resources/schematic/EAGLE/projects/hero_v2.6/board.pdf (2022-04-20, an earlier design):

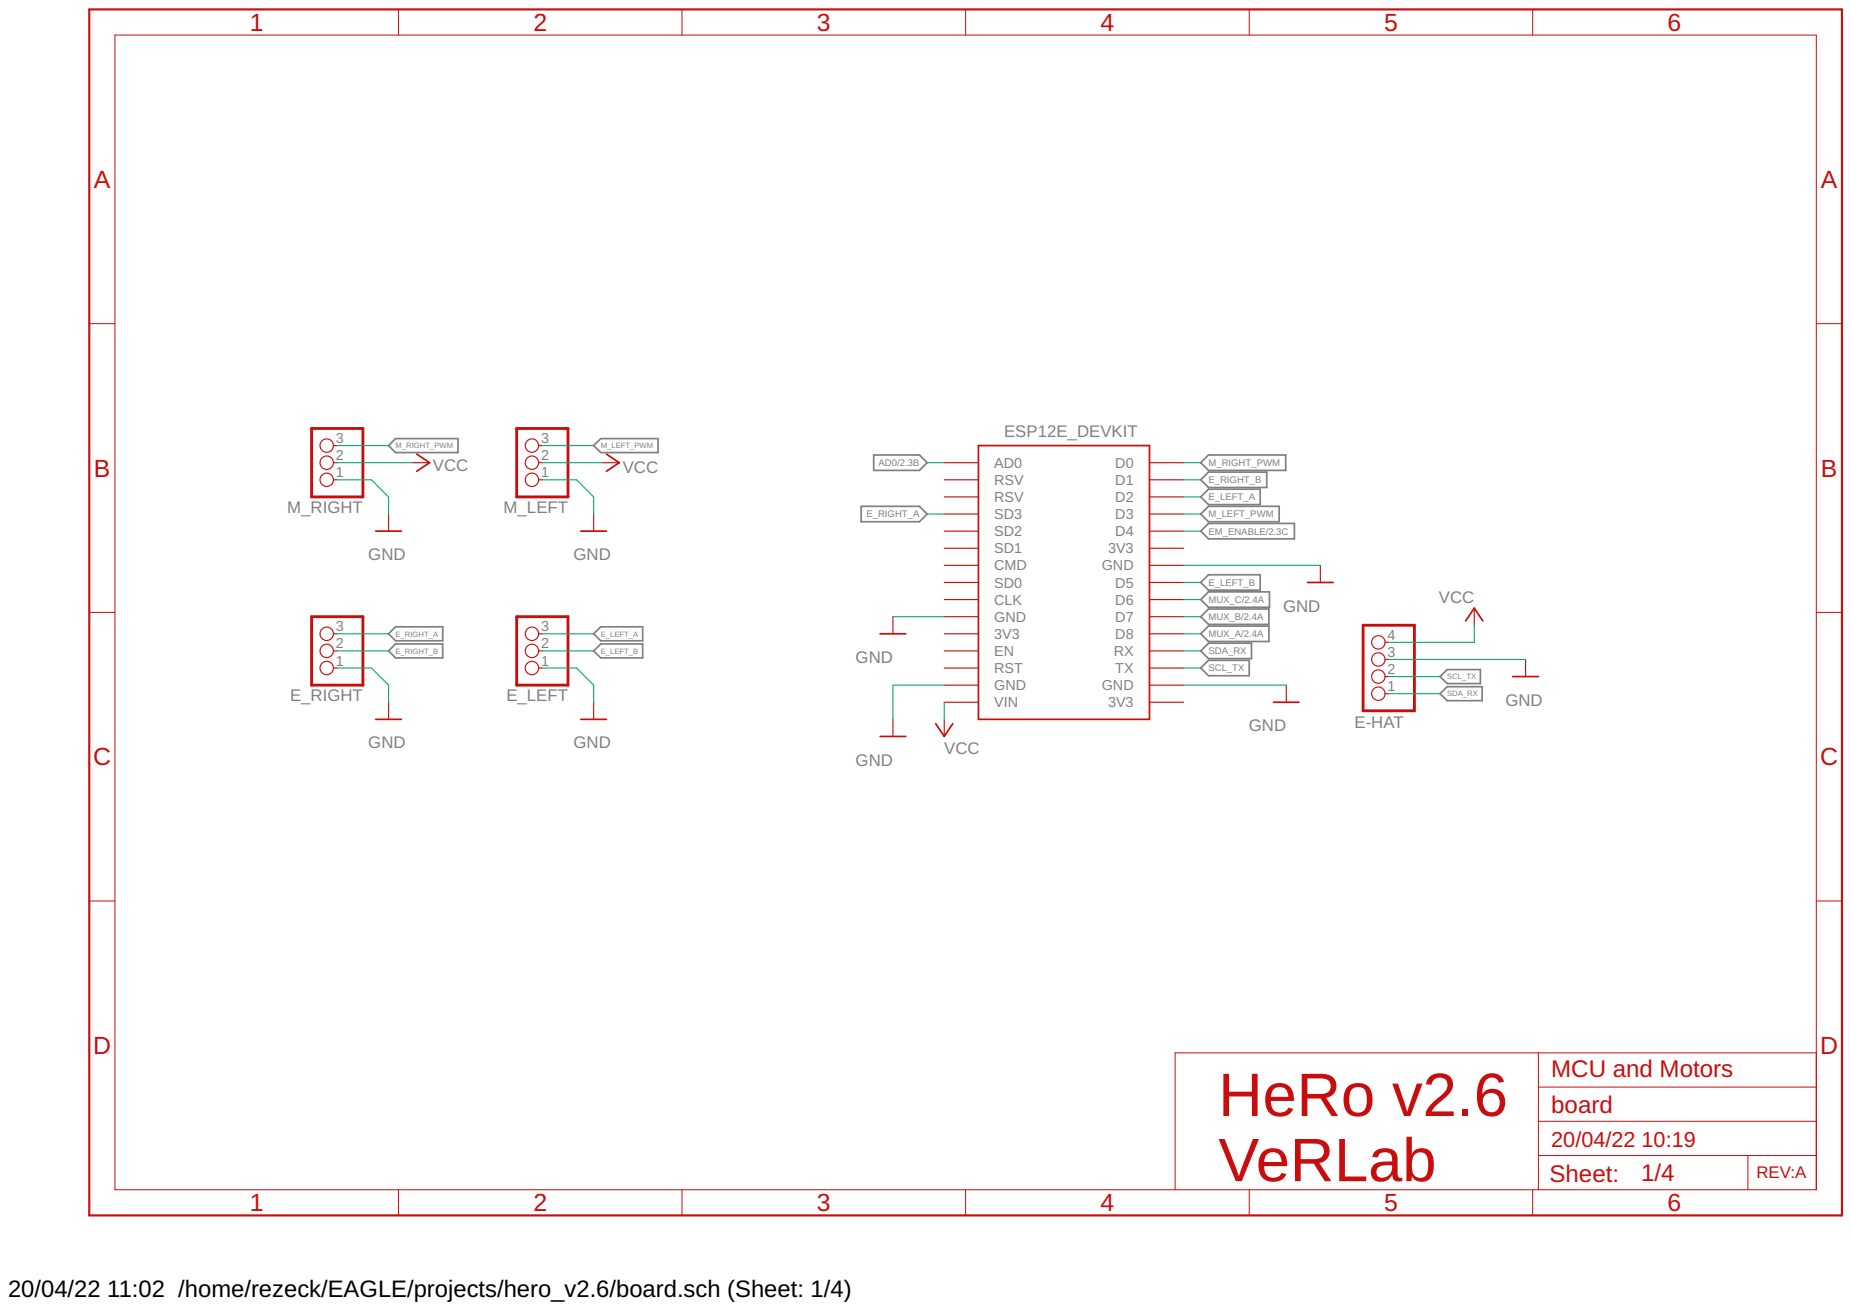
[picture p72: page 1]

20/04/22 11:02 /home/rezeck/EAGLE/projects/hero_v2.6/board.sch (Sheet: 1/4)

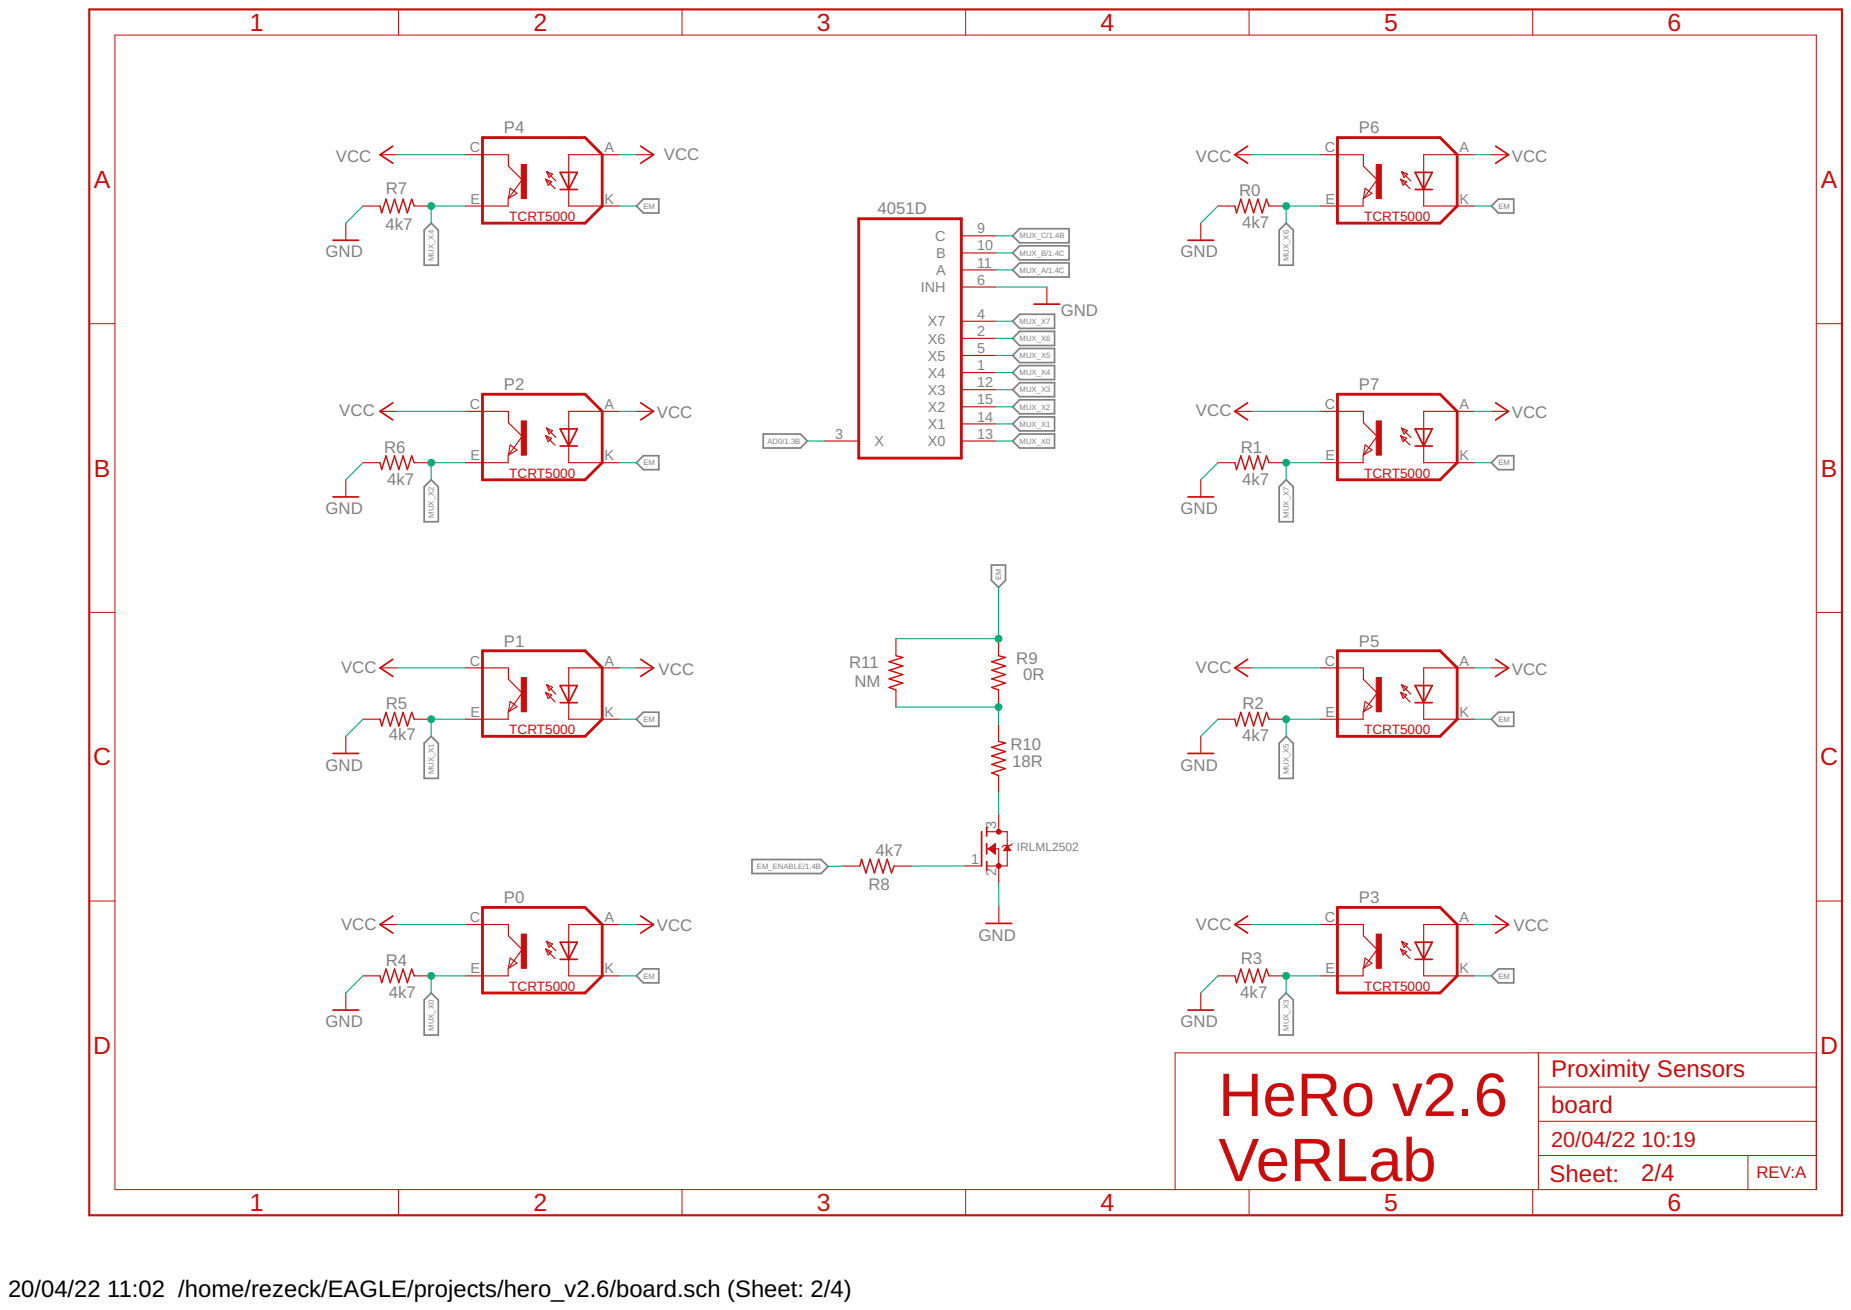
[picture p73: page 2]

20/04/22 11:02 /home/rezeck/EAGLE/projects/hero_v2.6/board.sch (Sheet: 2/4)

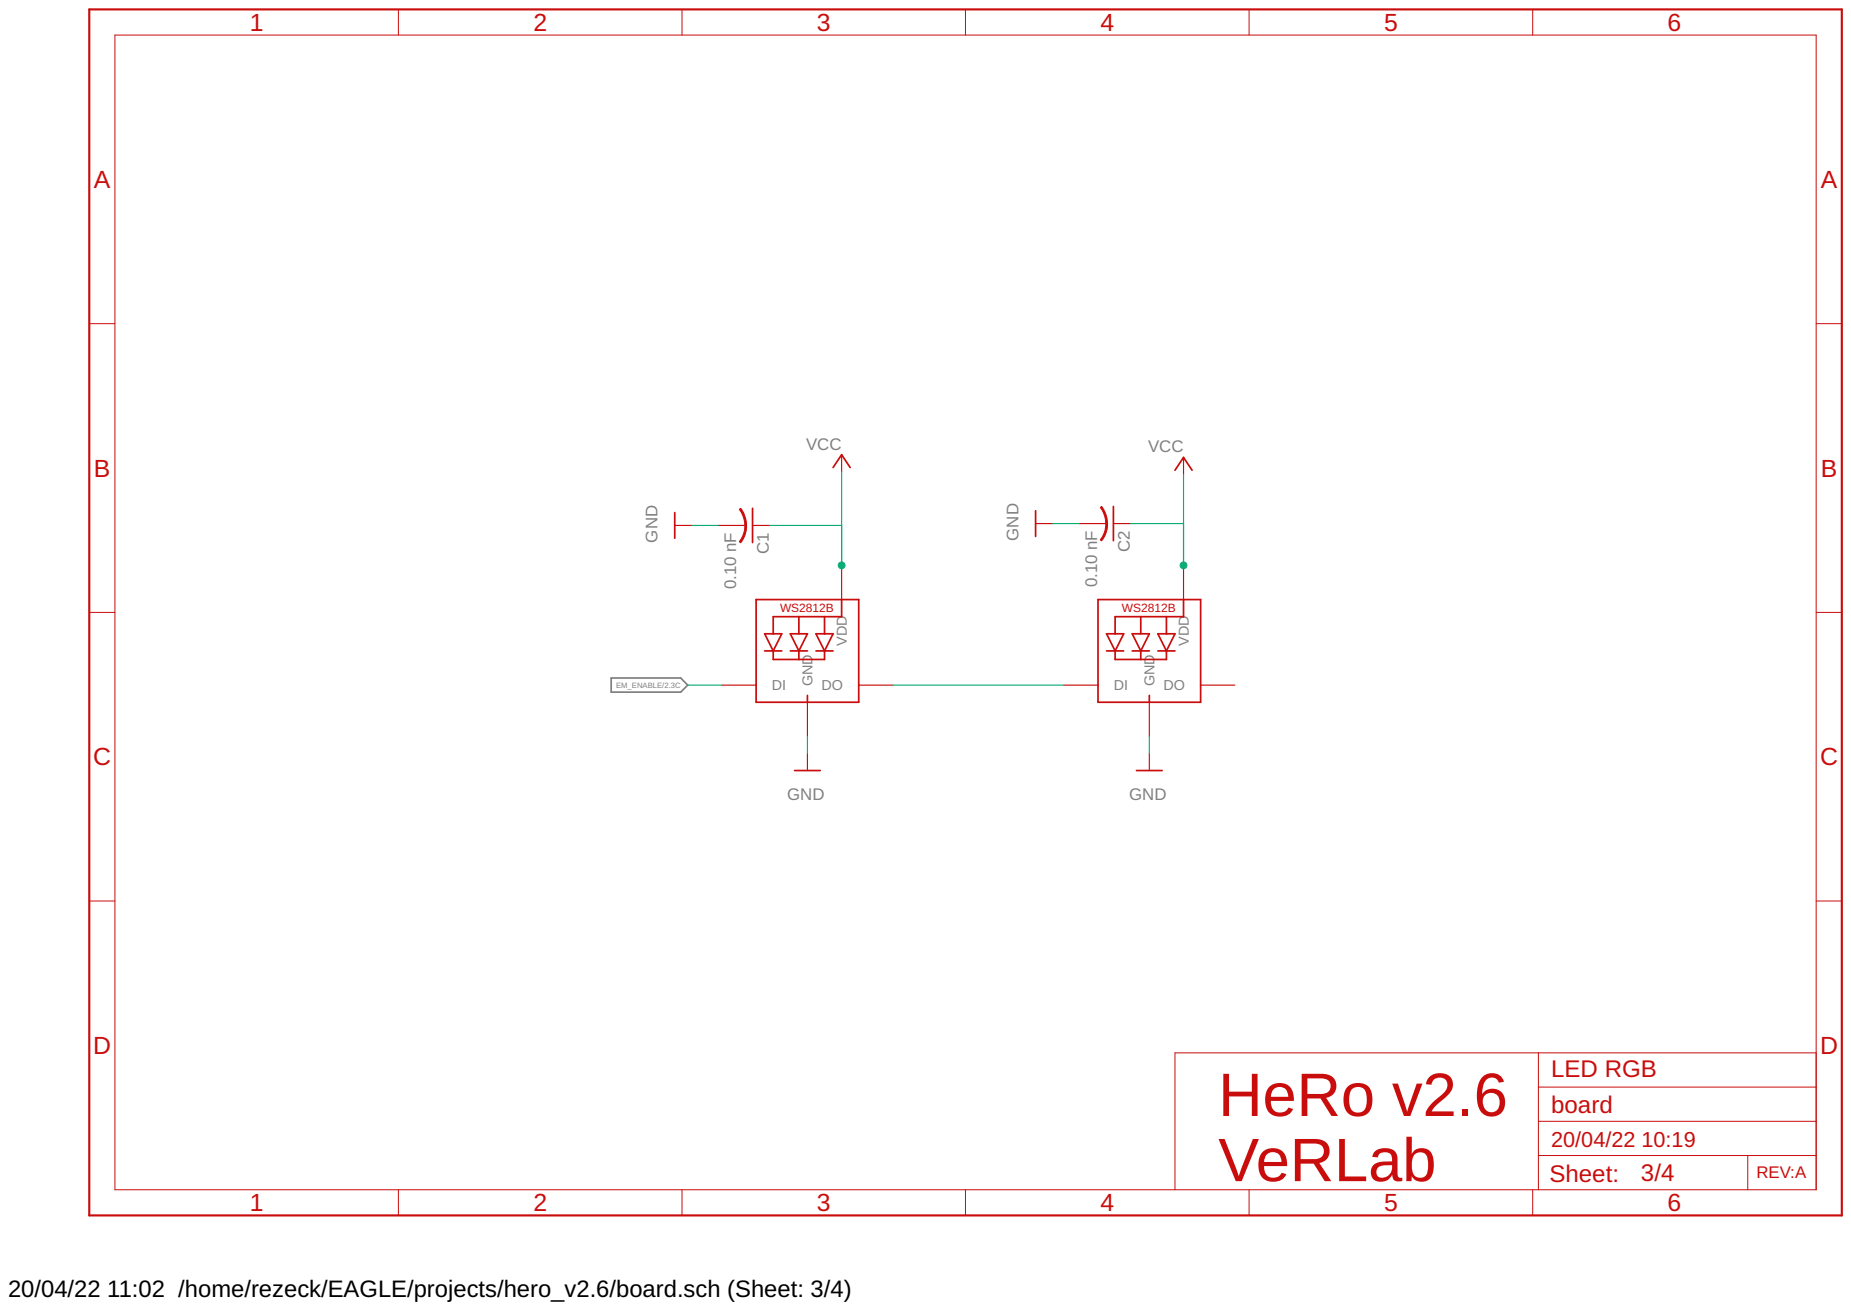
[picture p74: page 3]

20/04/22 11:02 /home/rezeck/EAGLE/projects/hero_v2.6/board.sch (Sheet: 3/4)

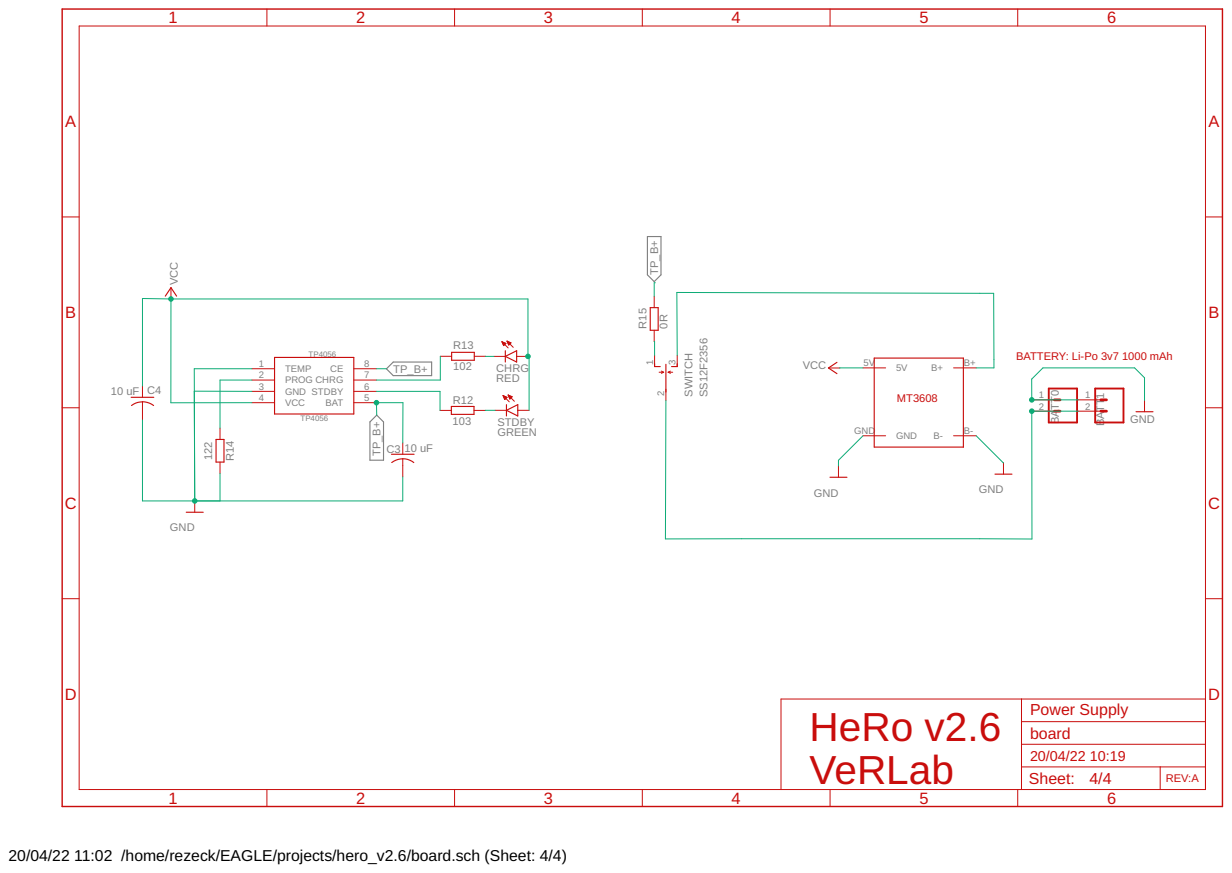
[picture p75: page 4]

BATTERY: Li-Po 3v7 1000 mAh

20/04/22 11:02 /home/rezeck/EAGLE/projects/hero_v2.6/board.sch (Sheet: 4/4)

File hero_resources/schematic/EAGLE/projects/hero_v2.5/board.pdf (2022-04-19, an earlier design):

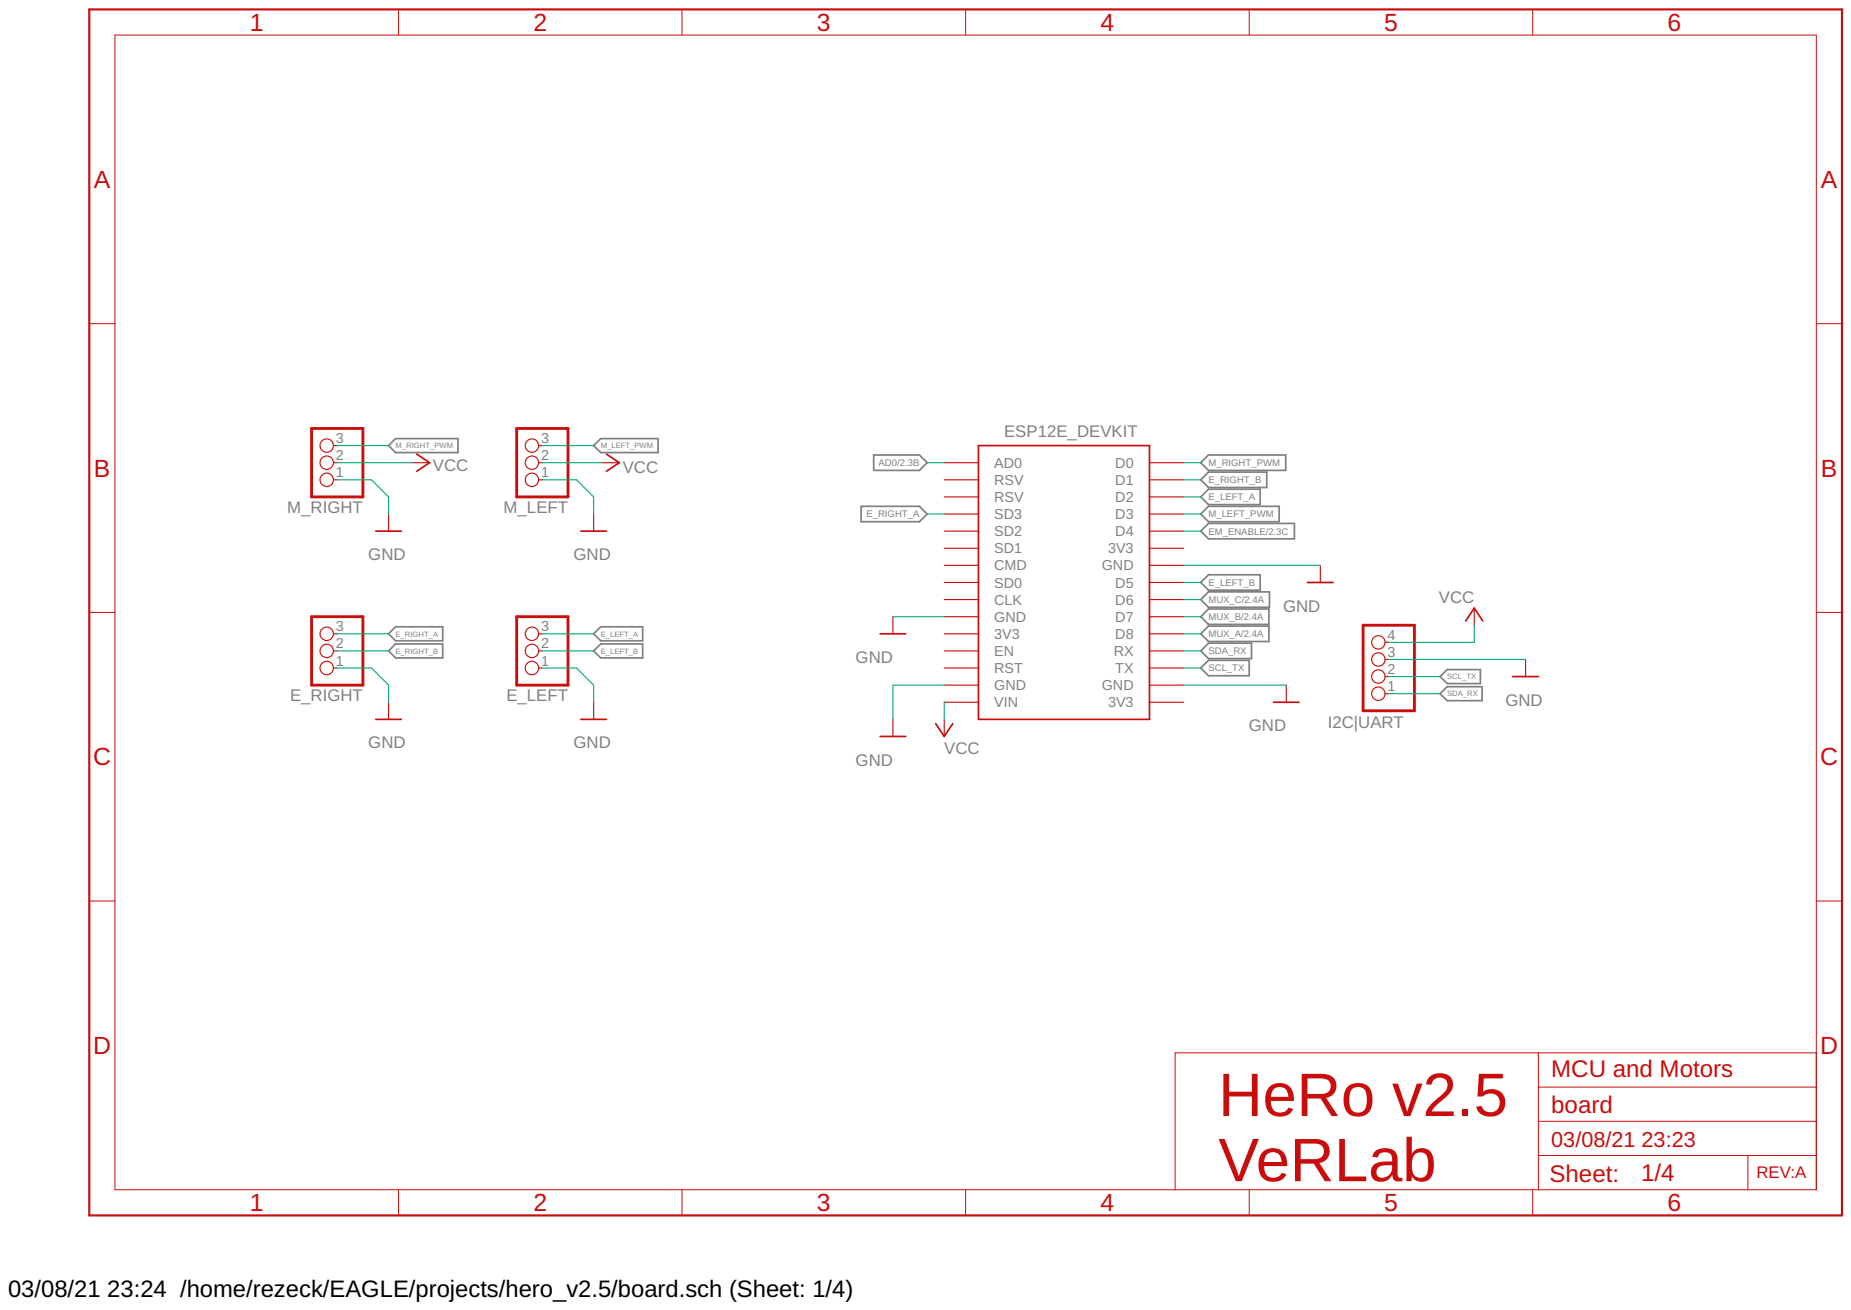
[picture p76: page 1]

03/08/21 23:24 /home/rezeck/EAGLE/projects/hero_v2.5/board.sch (Sheet: 1/4)

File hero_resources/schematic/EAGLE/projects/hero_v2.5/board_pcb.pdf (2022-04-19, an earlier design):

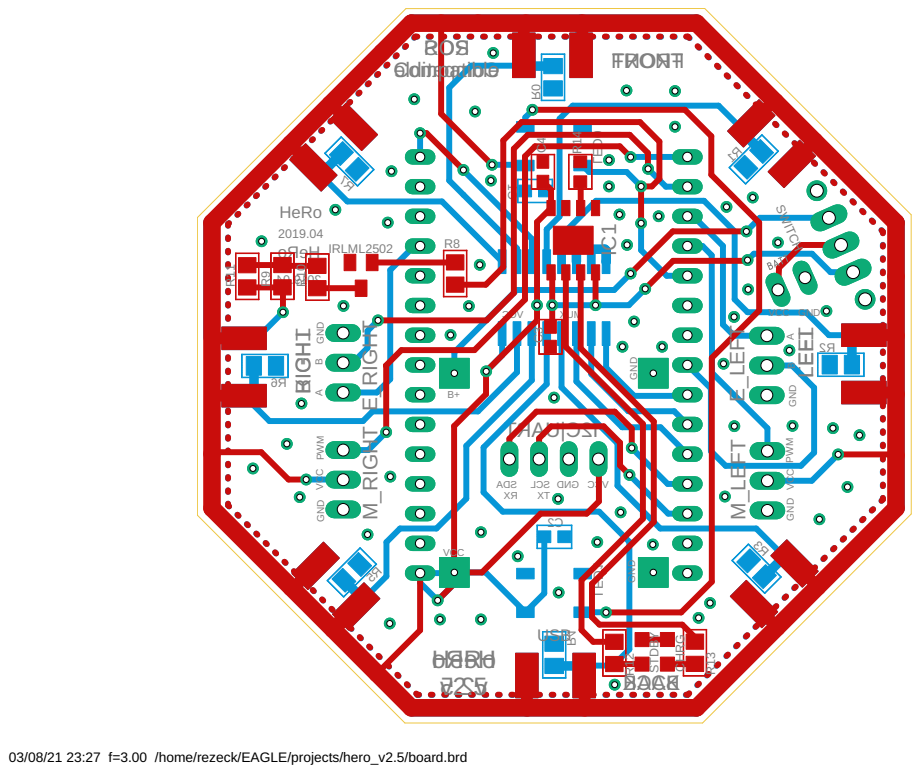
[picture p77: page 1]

03/08/21 23:27 f=3.00 /home/rezeck/EAGLE/projects/hero_v2.5/board.brd

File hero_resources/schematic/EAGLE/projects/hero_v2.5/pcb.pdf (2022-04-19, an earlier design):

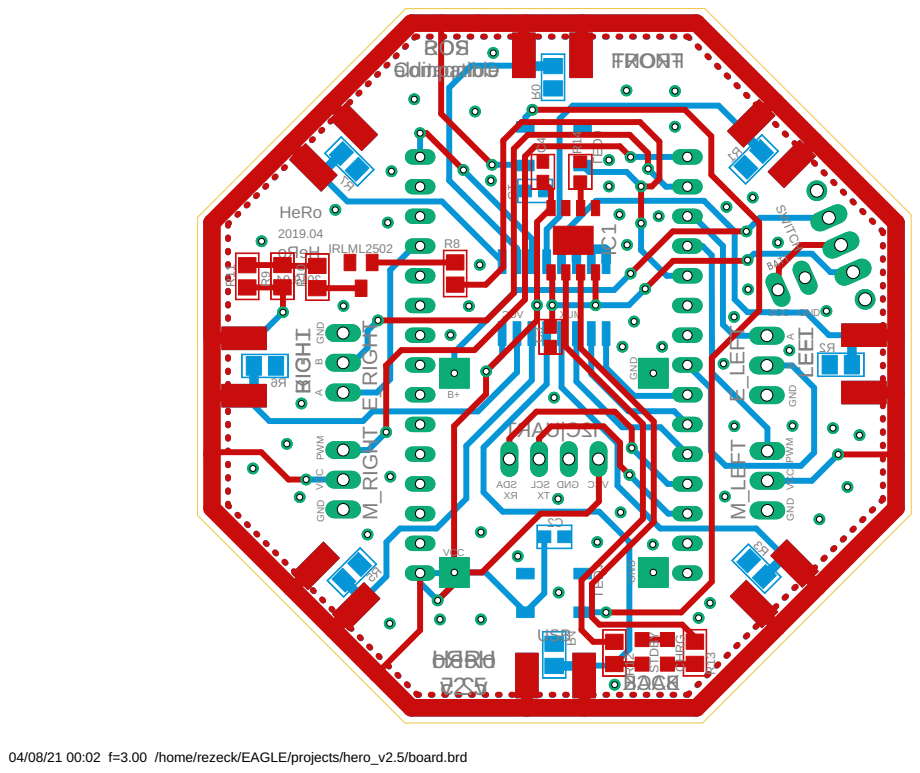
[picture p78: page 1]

04/08/21 00:02 f=3.00 /home/rezeck/EAGLE/projects/hero_v2.5/board.brd

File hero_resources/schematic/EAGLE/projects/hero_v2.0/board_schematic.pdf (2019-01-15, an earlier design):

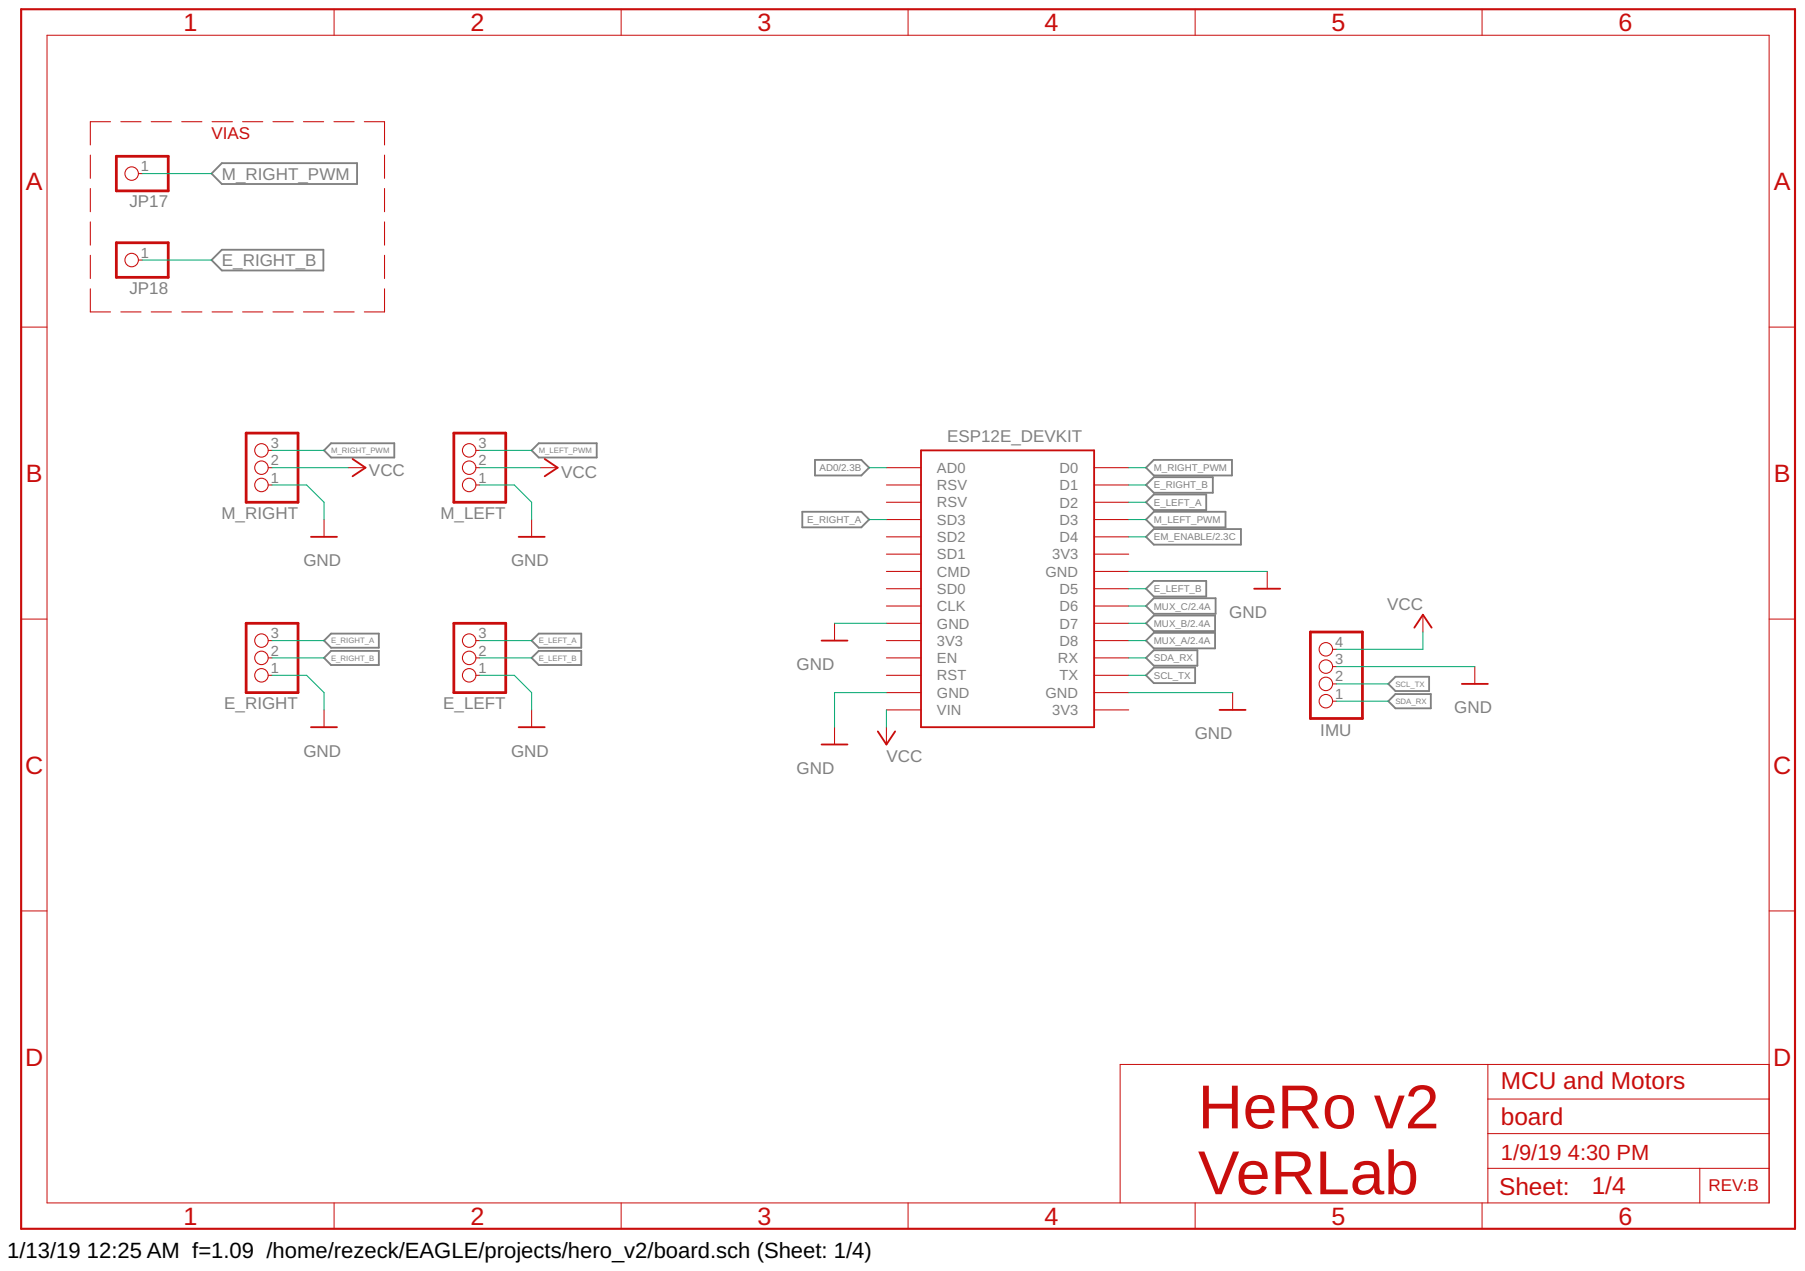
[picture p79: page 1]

1/13/19 12:25 AM f=1.09 /home/rezeck/EAGLE/projects/hero_v2/board.sch (Sheet: 1/4)


1/13/19 12:25 AM f=1.09 /home/rezeck/EAGLE/projects/hero_v2/board.sch (Sheet: 2/4)


1/13/19 12:25 AM f=1.09 /home/rezeck/EAGLE/projects/hero_v2/board.sch (Sheet: 3/4)


BATTERY: Li-Po 3v7 1000 mAh

1/13/19 12:25 AM f=1.09 /home/rezeck/EAGLE/projects/hero_v2/board.sch (Sheet: 4/4)

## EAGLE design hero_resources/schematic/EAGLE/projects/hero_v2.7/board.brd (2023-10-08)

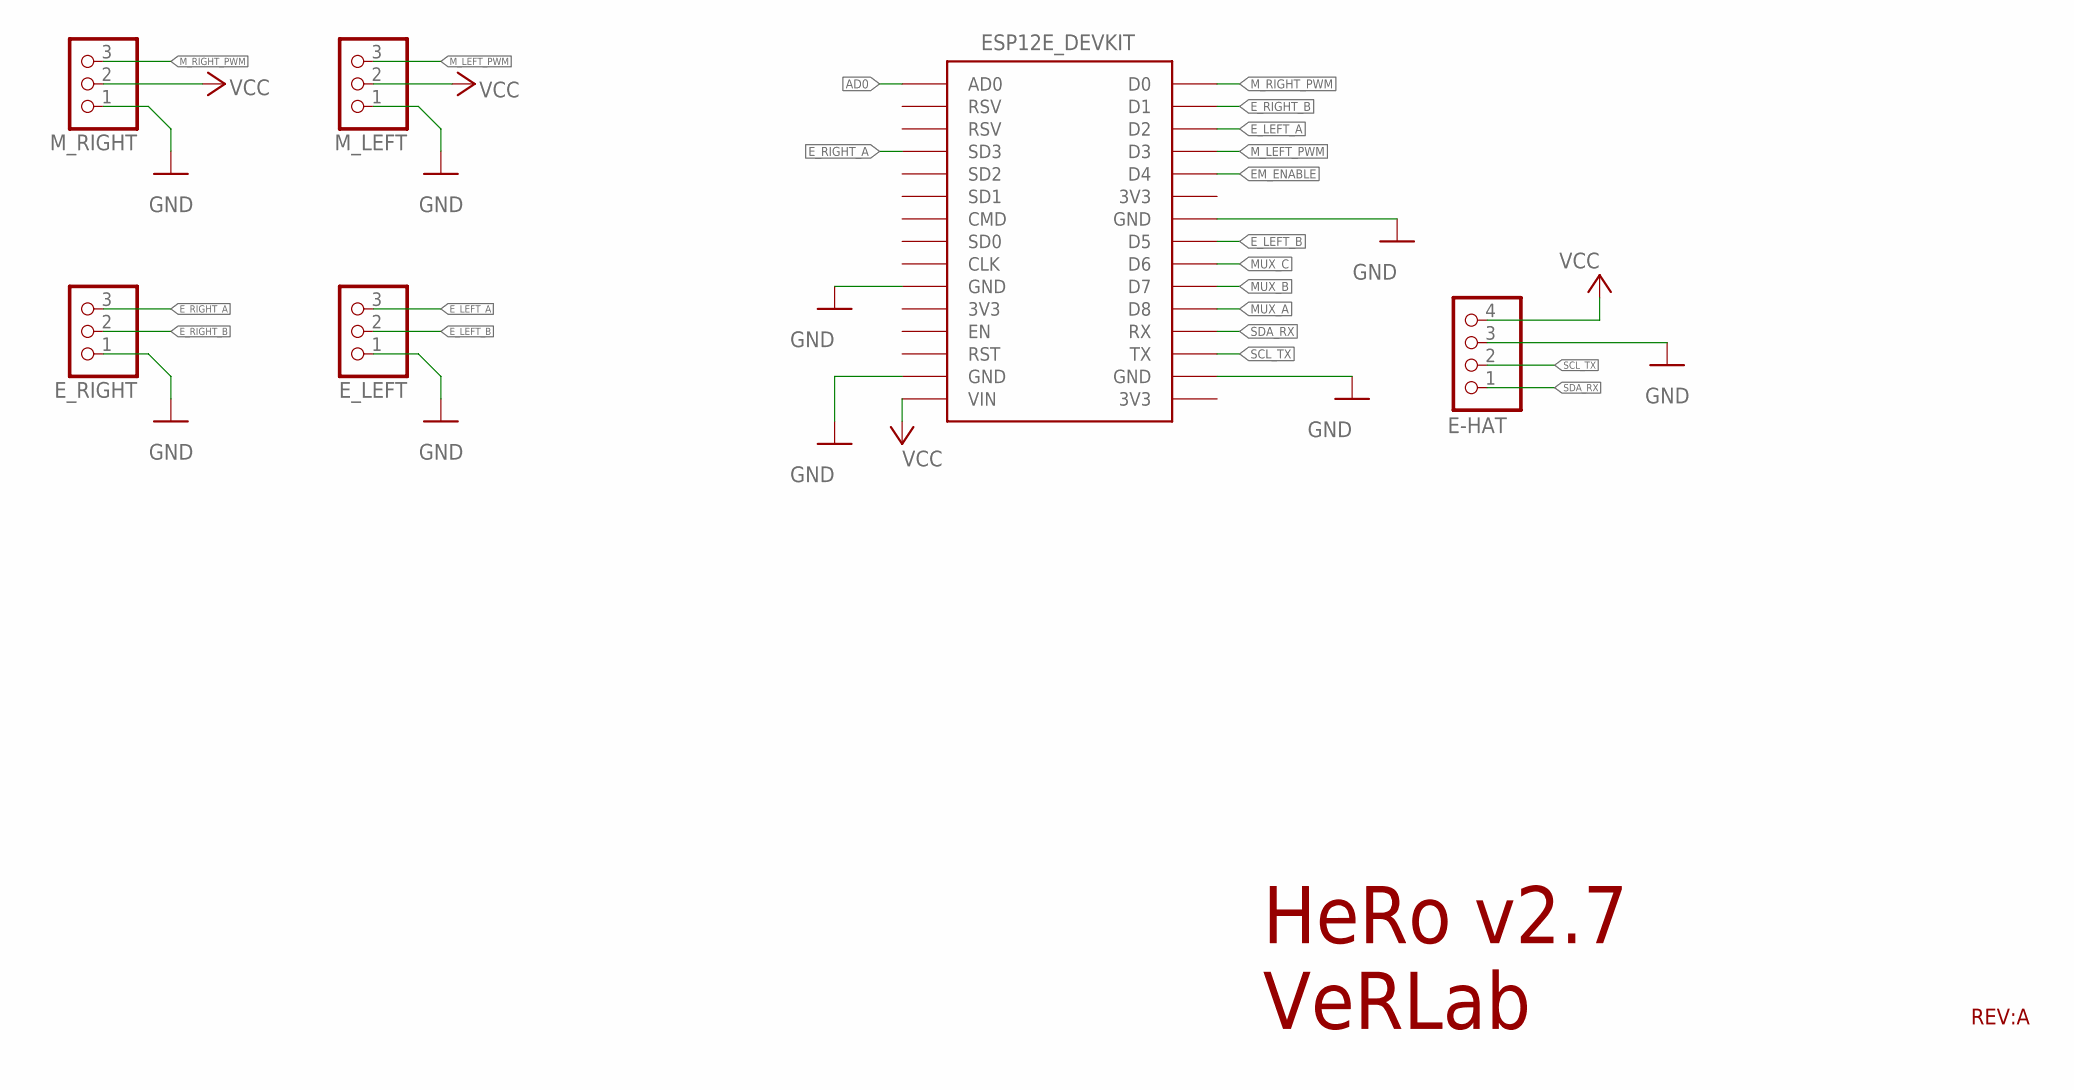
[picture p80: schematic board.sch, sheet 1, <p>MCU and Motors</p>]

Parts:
E-HAT: PINHD-1X4; 1X04
ESP-12E: ESP12E_DEVKIT
E_LEFT: PINHD-1X3; 1X03
E_RIGHT: PINHD-1X3; 1X03
M_LEFT: PINHD-1X3; 1X03
M_RIGHT: PINHD-1X3; 1X03

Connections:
AD0: ESP-12E.AD0; also elsewhere on the board
EM_ENABLE: ESP-12E.D4; also elsewhere on the board
E_LEFT_A: ESP-12E.D2, E_LEFT.3
E_LEFT_B: ESP-12E.D5, E_LEFT.2
E_RIGHT_A: ESP-12E.SD3, E_RIGHT.3
E_RIGHT_B: ESP-12E.D1, E_RIGHT.2
GND: E-HAT.3, ESP-12E.GND@0 (GND), ESP-12E.GND@1 (GND), ESP-12E.GND@2 (GND), ESP-12E.GND@3 (GND), E_LEFT.1, E_RIGHT.1, M_LEFT.1, M_RIGHT.1; also elsewhere on the board
MUX_A: ESP-12E.D8; also elsewhere on the board
MUX_B: ESP-12E.D7; also elsewhere on the board
MUX_C: ESP-12E.D6; also elsewhere on the board
M_LEFT_PWM: ESP-12E.D3, M_LEFT.3
M_RIGHT_PWM: ESP-12E.D0, M_RIGHT.3
SCL_TX: E-HAT.2, ESP-12E.TX
SDA_RX: E-HAT.1, ESP-12E.RX
VCC: E-HAT.4, ESP-12E.VIN, M_LEFT.2, M_RIGHT.2; also elsewhere on the board

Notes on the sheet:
HeRo v2.7 VeRLab
REV:A

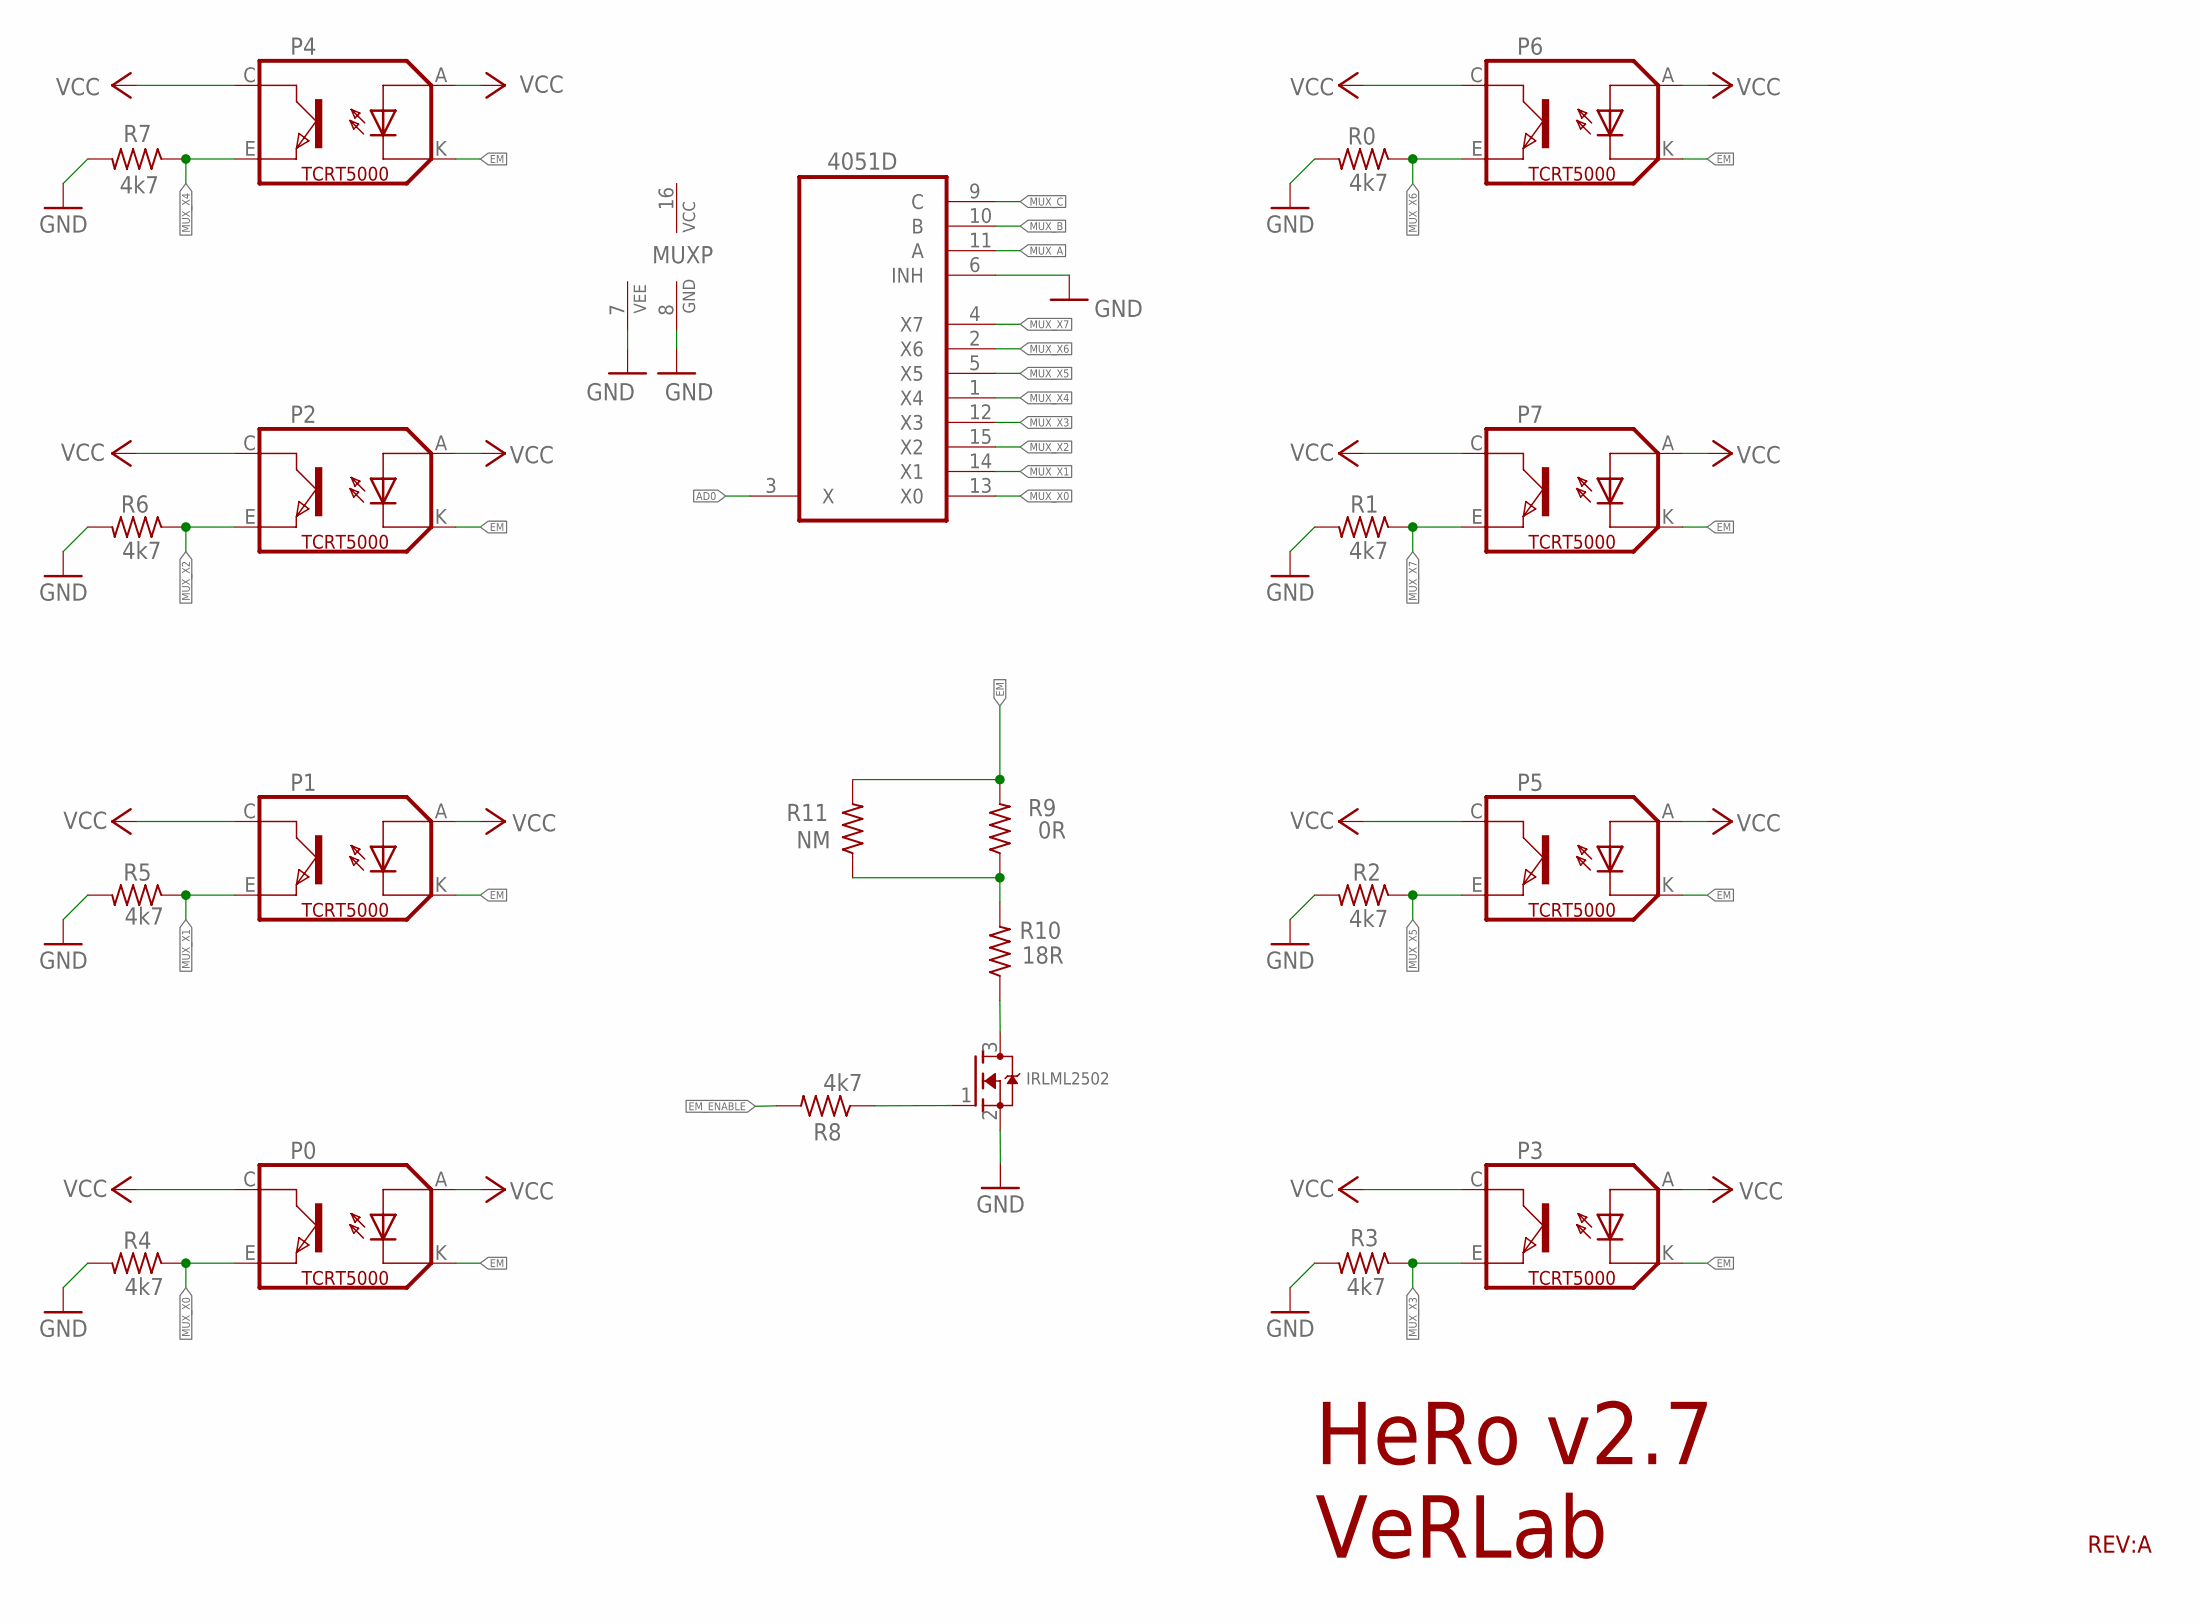
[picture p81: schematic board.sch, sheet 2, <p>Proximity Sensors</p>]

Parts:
IRLML2502: MOSFET-NREFLOW; SOT23
MUX: 4051D; SO16
P0, P1, P2, P3, P4, P5, P6, P7: TCRT5000
R0, R1, R2, R3, R4, R5, R6, R7: 4k7; M0805
R8: 4k7; R0805
R9: 0R; R0805
R10: 18R; R0805
R11: NM; R0805

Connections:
AD0: MUX.3 (X); also elsewhere on the board
EM: P0.K (CATHODE), P1.K (CATHODE), P2.K (CATHODE), P3.K (CATHODE), P4.K (CATHODE), P5.K (CATHODE), P6.K (CATHODE), P7.K (CATHODE), R9.2, R11.2
EM_ENABLE: R8.2; also elsewhere on the board
GND: IRLML2502.2 (S), MUX.6 (INH), MUX.7 (VEE), MUX.8 (GND), R0.2, R1.2, R2.2, R3.2, R4.2, R5.2, R6.2, R7.2; also elsewhere on the board
MUX_A: MUX.11 (A); also elsewhere on the board
MUX_B: MUX.10 (B); also elsewhere on the board
MUX_C: MUX.9 (C); also elsewhere on the board
MUX_X0: MUX.13 (X0), P0.E (EMITTER), R4.1
MUX_X1: MUX.14 (X1), P1.E (EMITTER), R5.1
MUX_X2: MUX.15 (X2), P2.E (EMITTER), R6.1
MUX_X3: MUX.12 (X3), P3.E (EMITTER), R3.1
MUX_X4: MUX.1 (X4), P4.E (EMITTER), R7.1
MUX_X5: MUX.5 (X5), P5.E (EMITTER), R2.1
MUX_X6: MUX.2 (X6), P6.E (EMITTER), R0.1
MUX_X7: MUX.4 (X7), P7.E (EMITTER), R1.1
unnamed: IRLML2502.3 (D), R10.1
unnamed: R9.1, R10.2, R11.1
unnamed: IRLML2502.1 (G), R8.1
VCC: MUX.16 (VCC), P0.A (ANODE), P0.C (COLLECTOR), P1.A (ANODE), P1.C (COLLECTOR), P2.A (ANODE), P2.C (COLLECTOR), P3.A (ANODE), P3.C (COLLECTOR), P4.A (ANODE), P4.C (COLLECTOR), P5.A (ANODE), P5.C (COLLECTOR), P6.A (ANODE), P6.C (COLLECTOR), P7.A (ANODE), P7.C (COLLECTOR); also elsewhere on the board

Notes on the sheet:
HeRo v2.7 VeRLab
REV:A

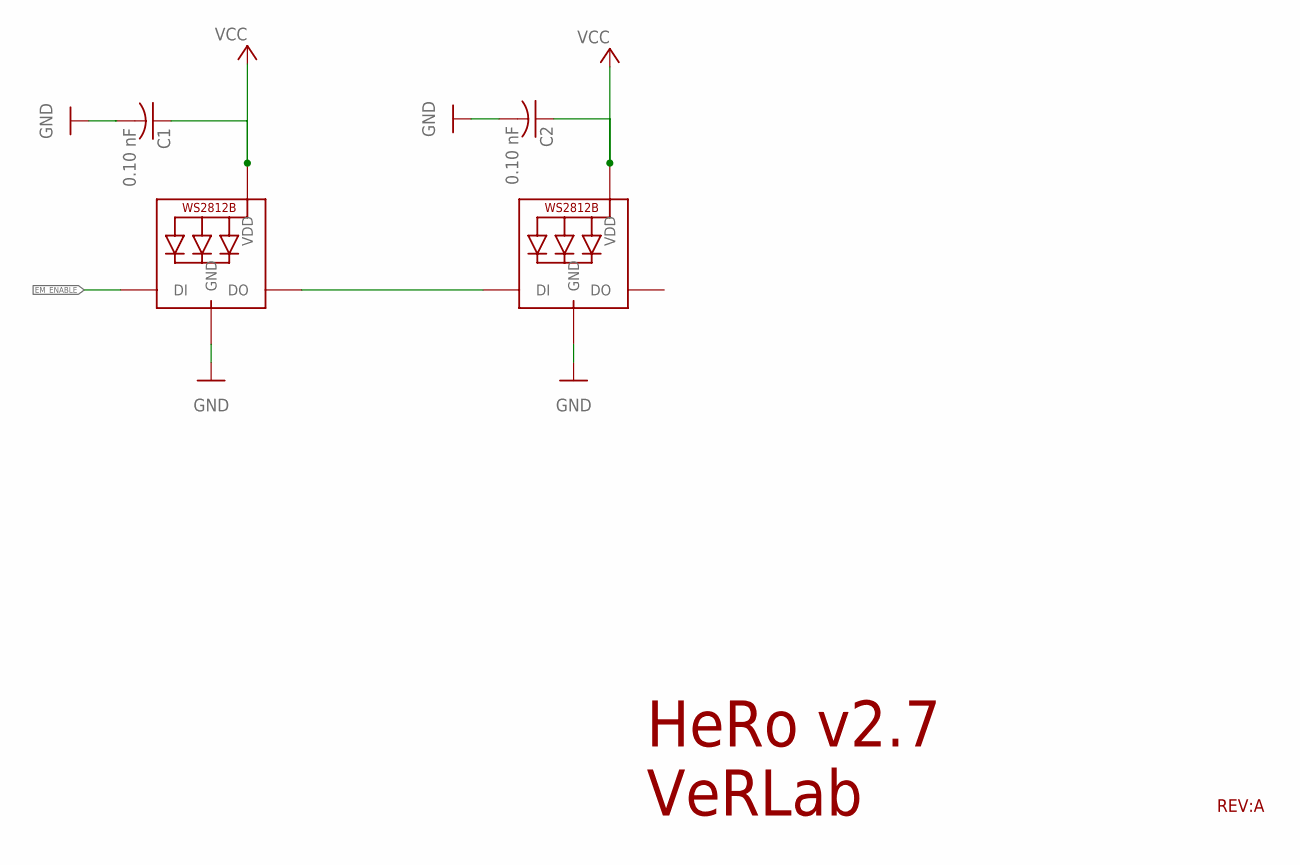
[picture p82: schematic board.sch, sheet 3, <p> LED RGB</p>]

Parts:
C1, C2: 0.10 nF; C0603
LED0, LED1: WS2812B5050; WS2812B

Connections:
EM_ENABLE: LED0.4-DIN (DI); also elsewhere on the board
GND: C1.2, C2.2, LED0.3-GND (GND), LED1.3-GND (GND); also elsewhere on the board
VCC: C1.1, C2.1, LED0.1-VDD (VDD), LED1.1-VDD (VDD); also elsewhere on the board
WS_OUT: LED0.2-DOUT (DO), LED1.4-DIN (DI)

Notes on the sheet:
HeRo v2.7 VeRLab
REV:A

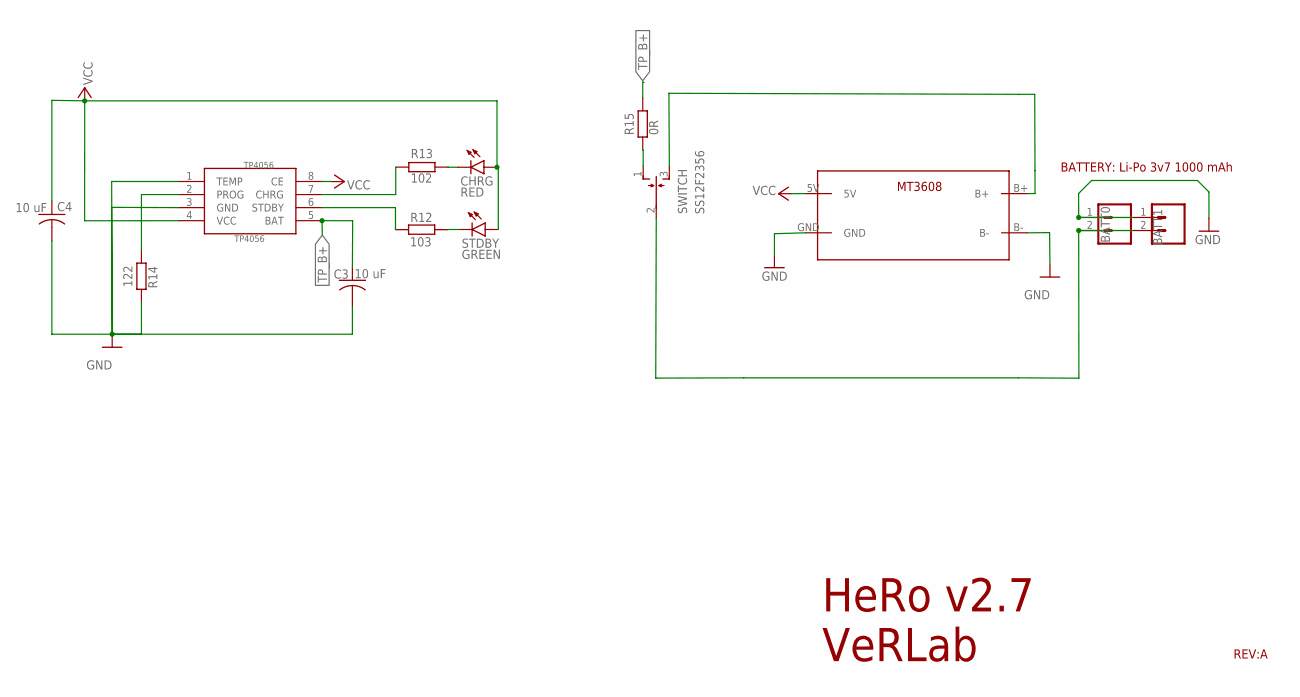
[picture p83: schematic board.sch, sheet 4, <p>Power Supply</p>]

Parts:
BATT0, BATT1: CONN_02JST-PTH-2; JST-2-PTH
C3, C4: 10 uF; C0603
CHRG: RED; SML0805
MT3608: MT3608
R12: 103; R0805
R13: 102; R0805
R14: 122; R0603
R15: 0R; R0805
STDBY: GREEN; SML0805
SWITCH: SS12F2356; HH3T90
TP4056: TP4056; SOP-8

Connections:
B+: MT3608.B+, SWITCH.3 (S)
CHRG: R13.1, TP4056.7 (CHRG)
GND: BATT0.1, BATT1.1, C3.2, C4.2, MT3608.B-, MT3608.GND, R14.1, TP4056.1 (TEMP), TP4056.3 (GND); also elsewhere on the board
unnamed: BATT0.2, BATT1.2, SWITCH.2
unnamed: CHRG.C, R13.2
unnamed: R12.2, STDBY.C
PROG: R14.2, TP4056.2 (PROG)
STDBY: R12.1, TP4056.6 (STDBY)
TP_B+: C3.1, R15.2, TP4056.5 (BAT)
TP_BS: R15.1, SWITCH.1 (O)
VCC: C4.1, CHRG.A, MT3608.5V, STDBY.A, TP4056.4 (VCC), TP4056.8 (CE); also elsewhere on the board

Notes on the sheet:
HeRo v2.7 VeRLab
BATTERY: Li-Po 3v7 1000 mAh
REV:A

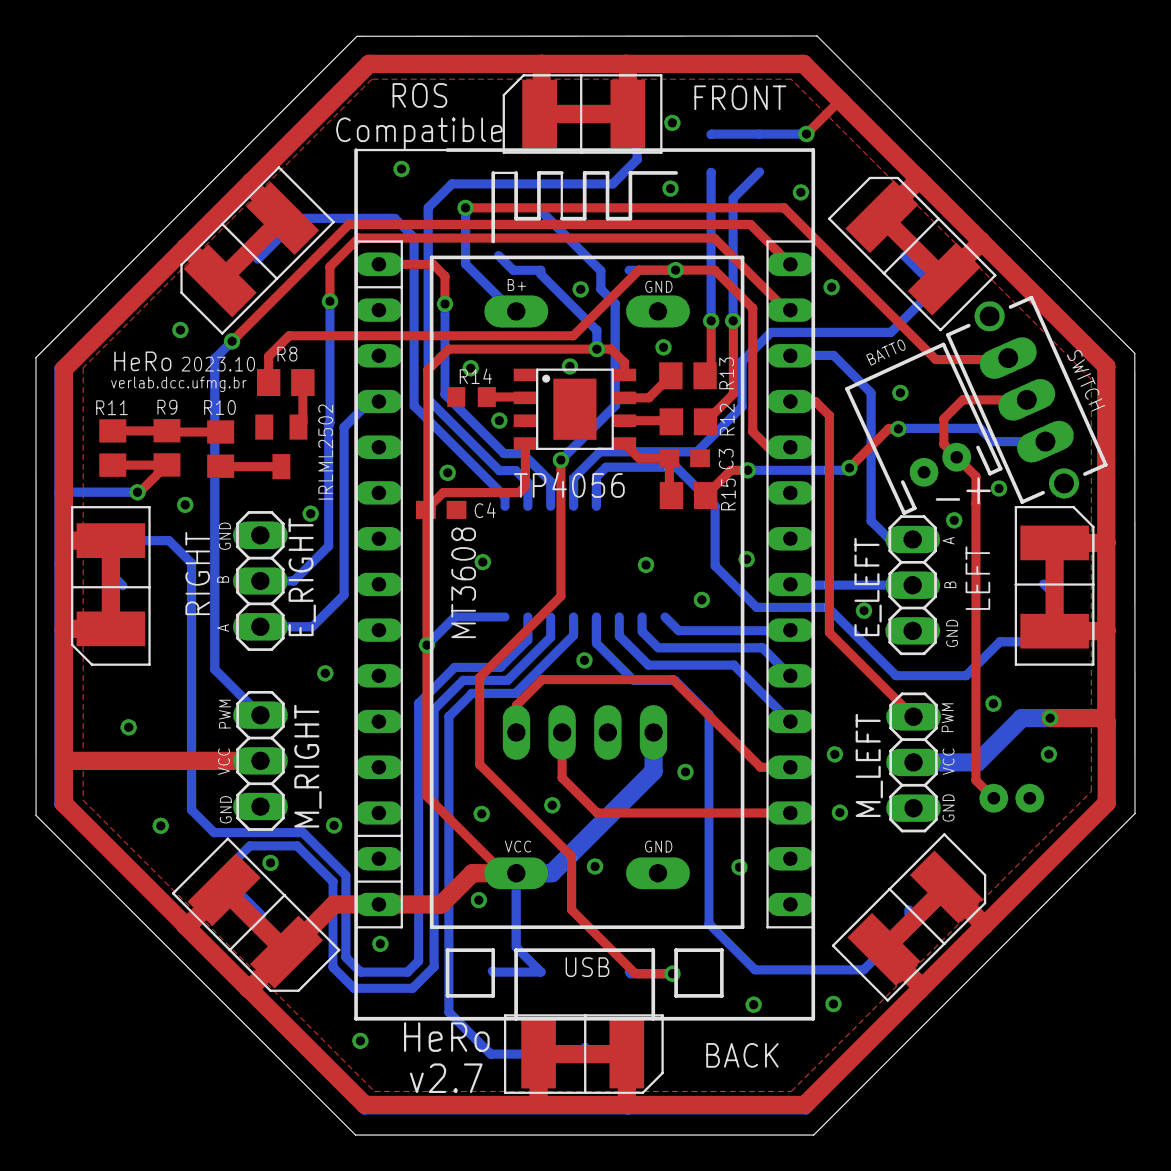
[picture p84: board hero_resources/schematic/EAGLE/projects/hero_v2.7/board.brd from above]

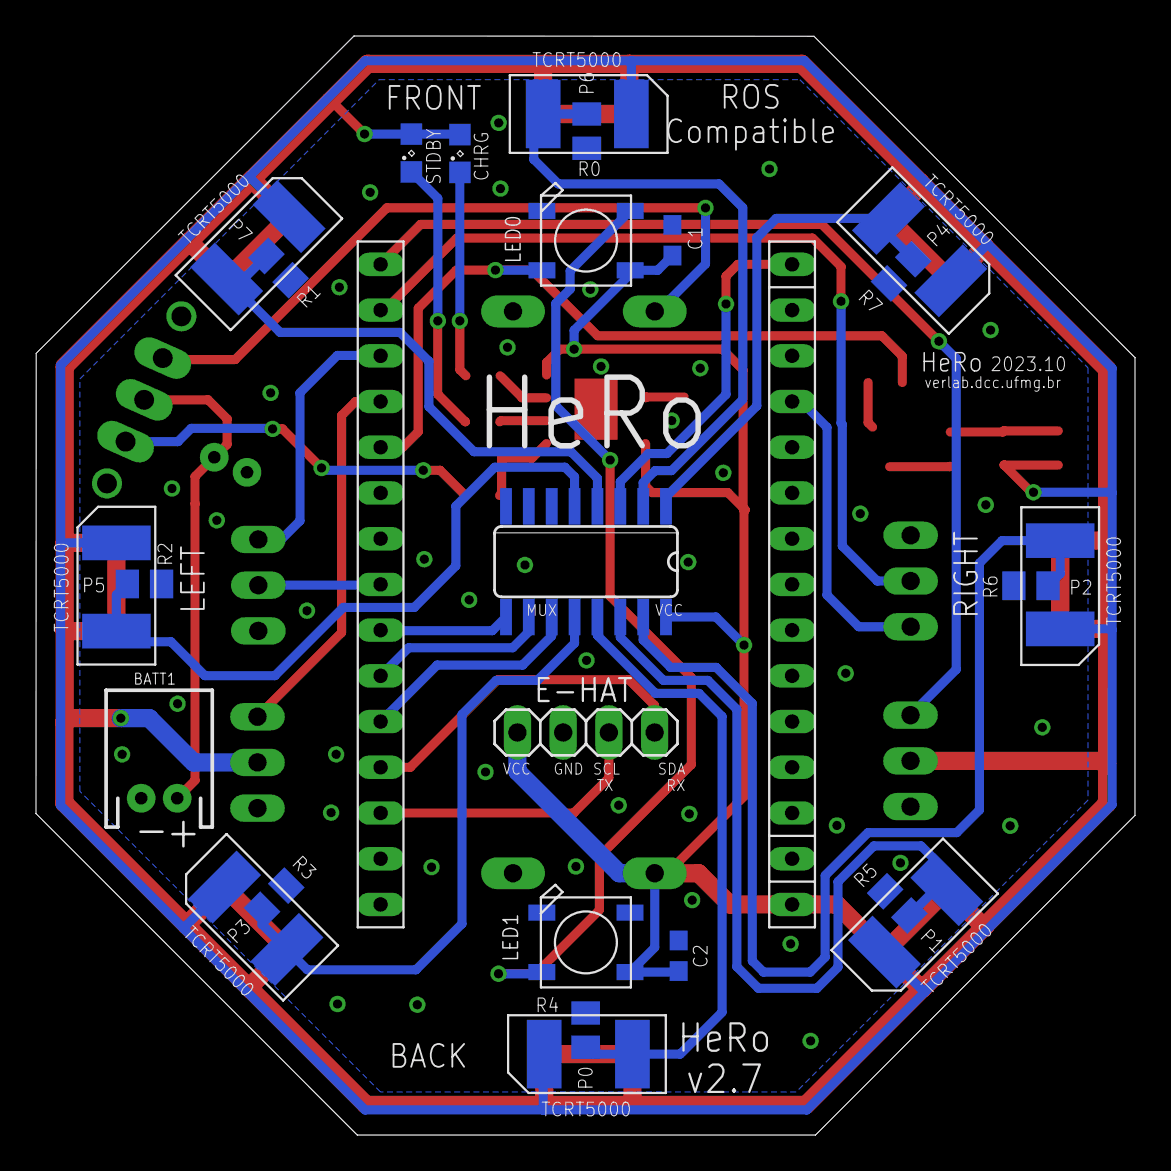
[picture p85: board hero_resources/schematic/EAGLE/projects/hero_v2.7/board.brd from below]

Board: 2 copper layers, 61.1 x 61.1 mm, 45 parts (25 on the bottom side), 37 nets.

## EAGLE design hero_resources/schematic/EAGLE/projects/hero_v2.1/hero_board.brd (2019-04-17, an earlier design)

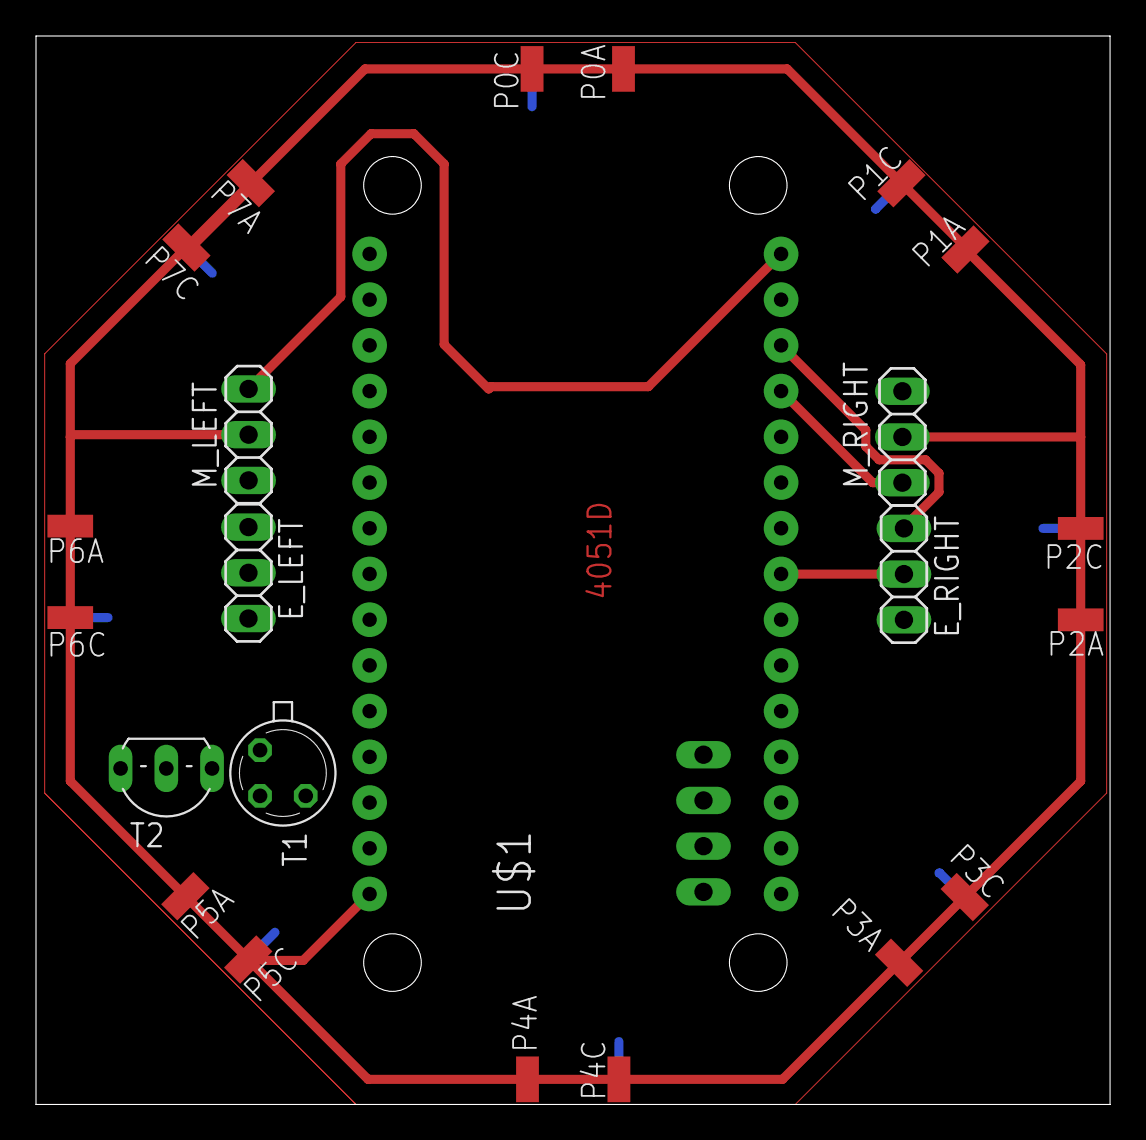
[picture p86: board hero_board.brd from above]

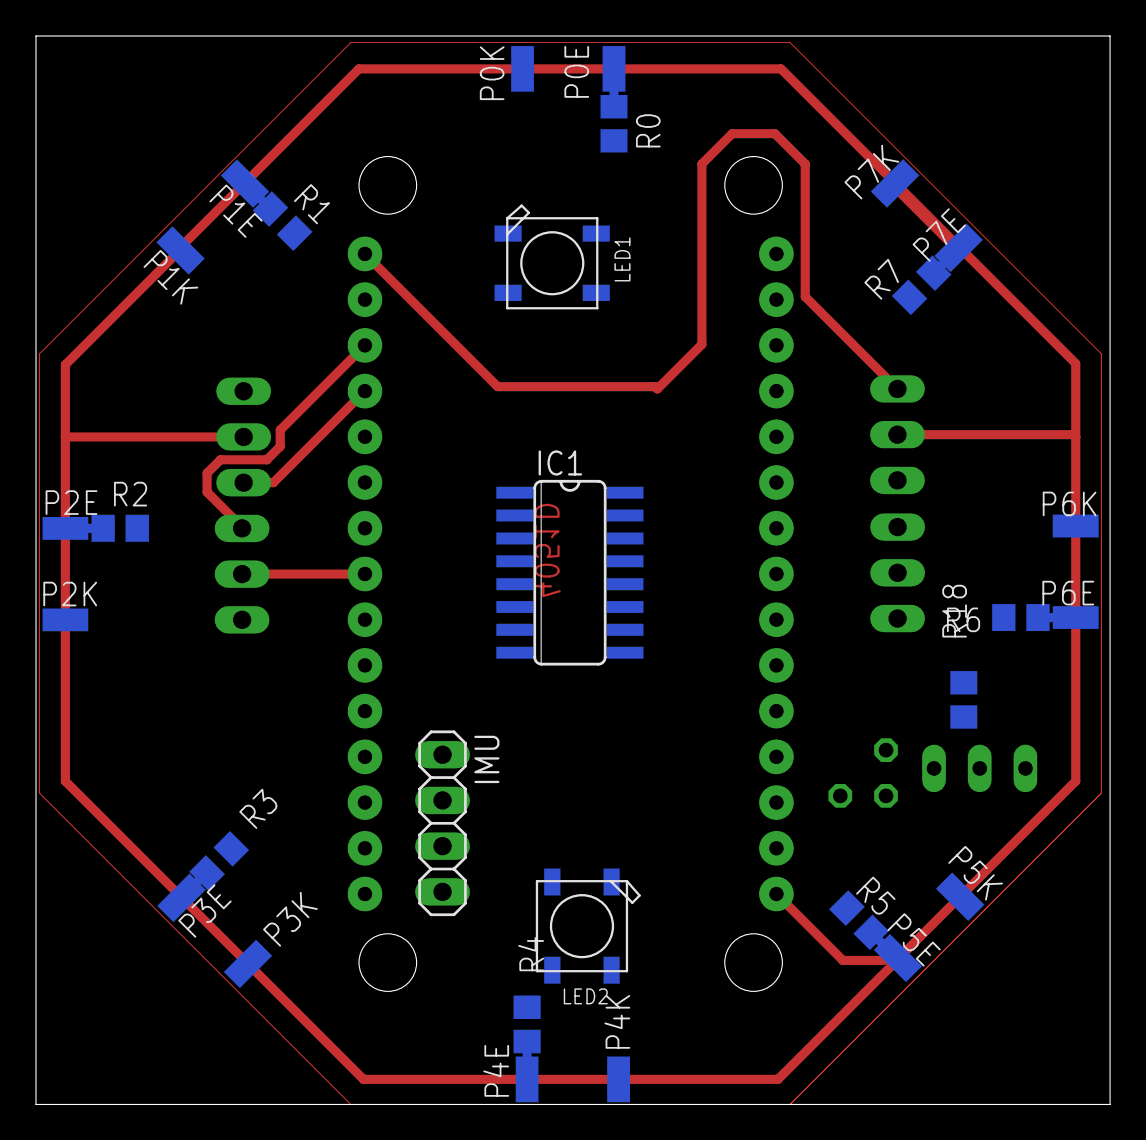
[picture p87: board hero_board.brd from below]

Board: 2 copper layers, 59.7 x 59.4 mm, 52 parts (29 on the bottom side), 27 nets.

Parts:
E_LEFT: 1X03
E_RIGHT: 1X03
IC1: 4051D; SO16
IMU: 1X04
LED1, LED2: WS2812B5050; WS2812B
M_LEFT: 1X03
M_RIGHT: 1X03
P0A, P0C, P0E, P0K, P1A, P1C, P1E, P1K, P2A, P2C, P2E, P2K, P3A, P3C, P3E, P3K, P4A, P4C, P4E, P4K, P5A, P5C, P5E, P5K, P6A, P6C, P6E, P6K, P7A, P7C, P7E, P7K: SMD1,27-2,54
R0, R1, R2, R3, R4, R5, R6, R7, R18: R0805
T1: 2N2222; TO18
T2: TO92-CBE
U$1: ESP12E_DEVKIT

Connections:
AD0: IC1.3, U$1.AD0
EM: P0K.1, P1K.1, P2K.1, P3K.1, P4K.1, P5K.1, P6K.1, P7K.1, R18.2
EM_ENABLE: LED1.4-DIN, T2.B, U$1.D4
E_LEFT_A: E_LEFT.3, U$1.SD3
E_LEFT_B: E_LEFT.2, U$1.D1
E_RIGHT_A: E_RIGHT.3, U$1.D2
E_RIGHT_B: E_RIGHT.2, U$1.D5
GND: E_LEFT.1, E_RIGHT.1, IC1.6, IC1.8, IMU.3, LED1.3-GND, LED2.3-GND, M_LEFT.1, M_RIGHT.1, R0.2, R1.2, R2.2, R3.2, R4.2, R5.2, R6.2, R7.2, T1.1, U$1.GND@1
MUX_A: IC1.11, U$1.D6
MUX_B: IC1.10, U$1.D7
MUX_C: IC1.9, U$1.D8
MUX_X0: IC1.13, P0E.1, R0.1
MUX_X1: IC1.14, P1E.1, R1.1
MUX_X2: IC1.15, P2E.1, R2.1
MUX_X3: IC1.12, P3E.1, R3.1
MUX_X4: IC1.1, P4E.1, R4.1
MUX_X5: IC1.5, P5E.1, R5.1
MUX_X6: IC1.2, P6E.1, R6.1
MUX_X7: IC1.4, P7E.1, R7.1
M_LEFT_PWM: M_LEFT.3, U$1.D0
M_RIGHT_PWM: M_RIGHT.3, U$1.D3
unnamed: T1.2, T2.E
unnamed: R18.1, T1.3, T2.C
unnamed: LED1.2-DOUT, LED2.4-DIN
SCL_TX: IMU.2, U$1.TX
SDA_RX: IMU.1, U$1.RX
VCC: IC1.16, IMU.4, LED1.1-VDD, LED2.1-VDD, M_LEFT.2, M_RIGHT.2, P0A.1, P0C.1, P1A.1, P1C.1, P2A.1, P2C.1, P3A.1, P3C.1, P4A.1, P4C.1, P5A.1, P5C.1, P6A.1, P6C.1, P7A.1, P7C.1, U$1.VIN

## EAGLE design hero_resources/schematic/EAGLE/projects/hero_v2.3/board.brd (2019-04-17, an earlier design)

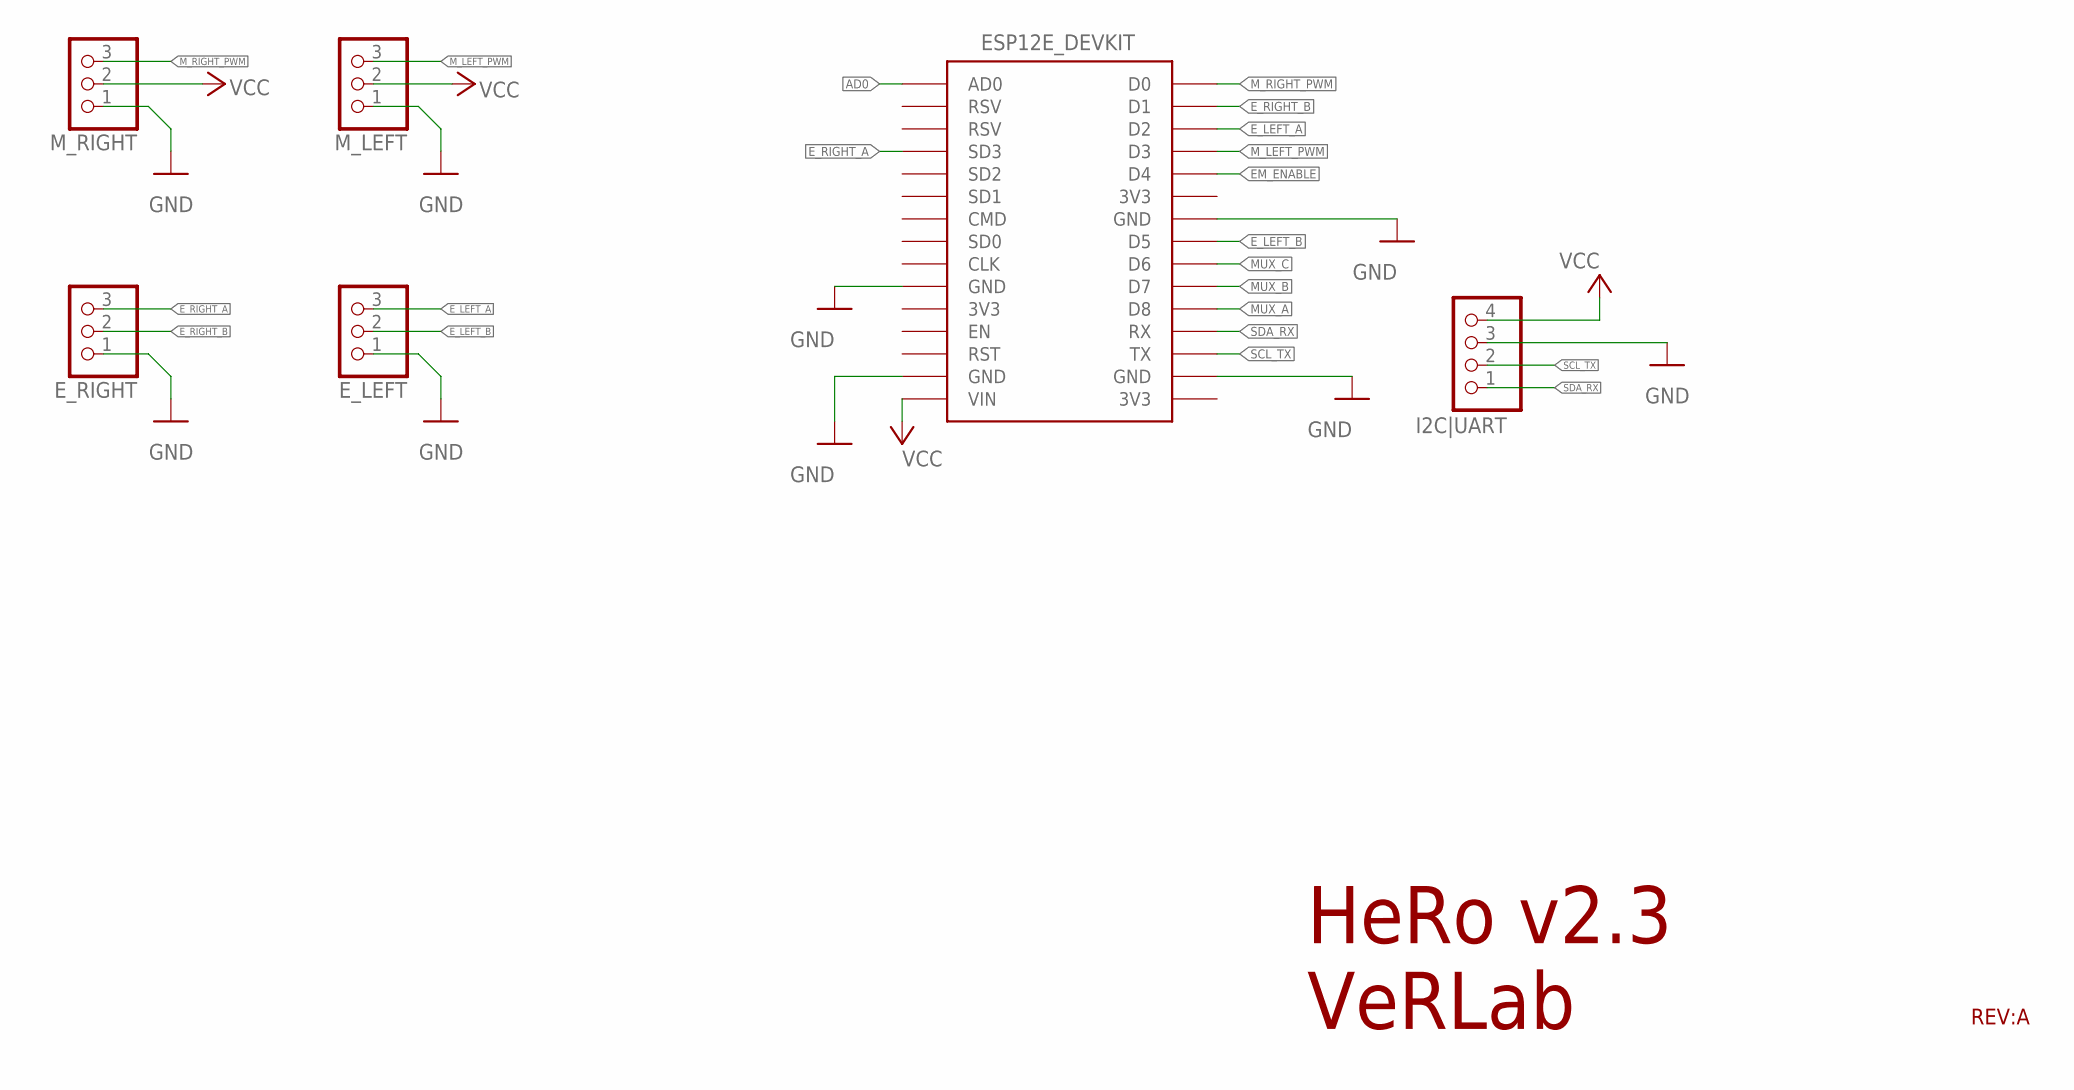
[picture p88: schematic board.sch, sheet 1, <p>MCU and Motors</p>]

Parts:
E_LEFT: PINHD-1X3; 1X03
E_RIGHT: PINHD-1X3; 1X03
I2C|UART: PINHD-1X4; 1X04
M_LEFT: PINHD-1X3; 1X03
M_RIGHT: PINHD-1X3; 1X03
U$1: ESP12E_DEVKIT

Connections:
AD0: U$1.AD0; also elsewhere on the board
EM_ENABLE: U$1.D4; also elsewhere on the board
E_LEFT_A: E_LEFT.3, U$1.D2
E_LEFT_B: E_LEFT.2, U$1.D5
E_RIGHT_A: E_RIGHT.3, U$1.SD3
E_RIGHT_B: E_RIGHT.2, U$1.D1
GND: E_LEFT.1, E_RIGHT.1, I2C|UART.3, M_LEFT.1, M_RIGHT.1, U$1.GND@0 (GND), U$1.GND@1 (GND), U$1.GND@2 (GND), U$1.GND@3 (GND); also elsewhere on the board
MUX_A: U$1.D8; also elsewhere on the board
MUX_B: U$1.D7; also elsewhere on the board
MUX_C: U$1.D6; also elsewhere on the board
M_LEFT_PWM: M_LEFT.3, U$1.D3
M_RIGHT_PWM: M_RIGHT.3, U$1.D0
SCL_TX: I2C|UART.2, U$1.TX
SDA_RX: I2C|UART.1, U$1.RX
VCC: I2C|UART.4, M_LEFT.2, M_RIGHT.2, U$1.VIN; also elsewhere on the board

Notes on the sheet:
HeRo v2.3 VeRLab
REV:A

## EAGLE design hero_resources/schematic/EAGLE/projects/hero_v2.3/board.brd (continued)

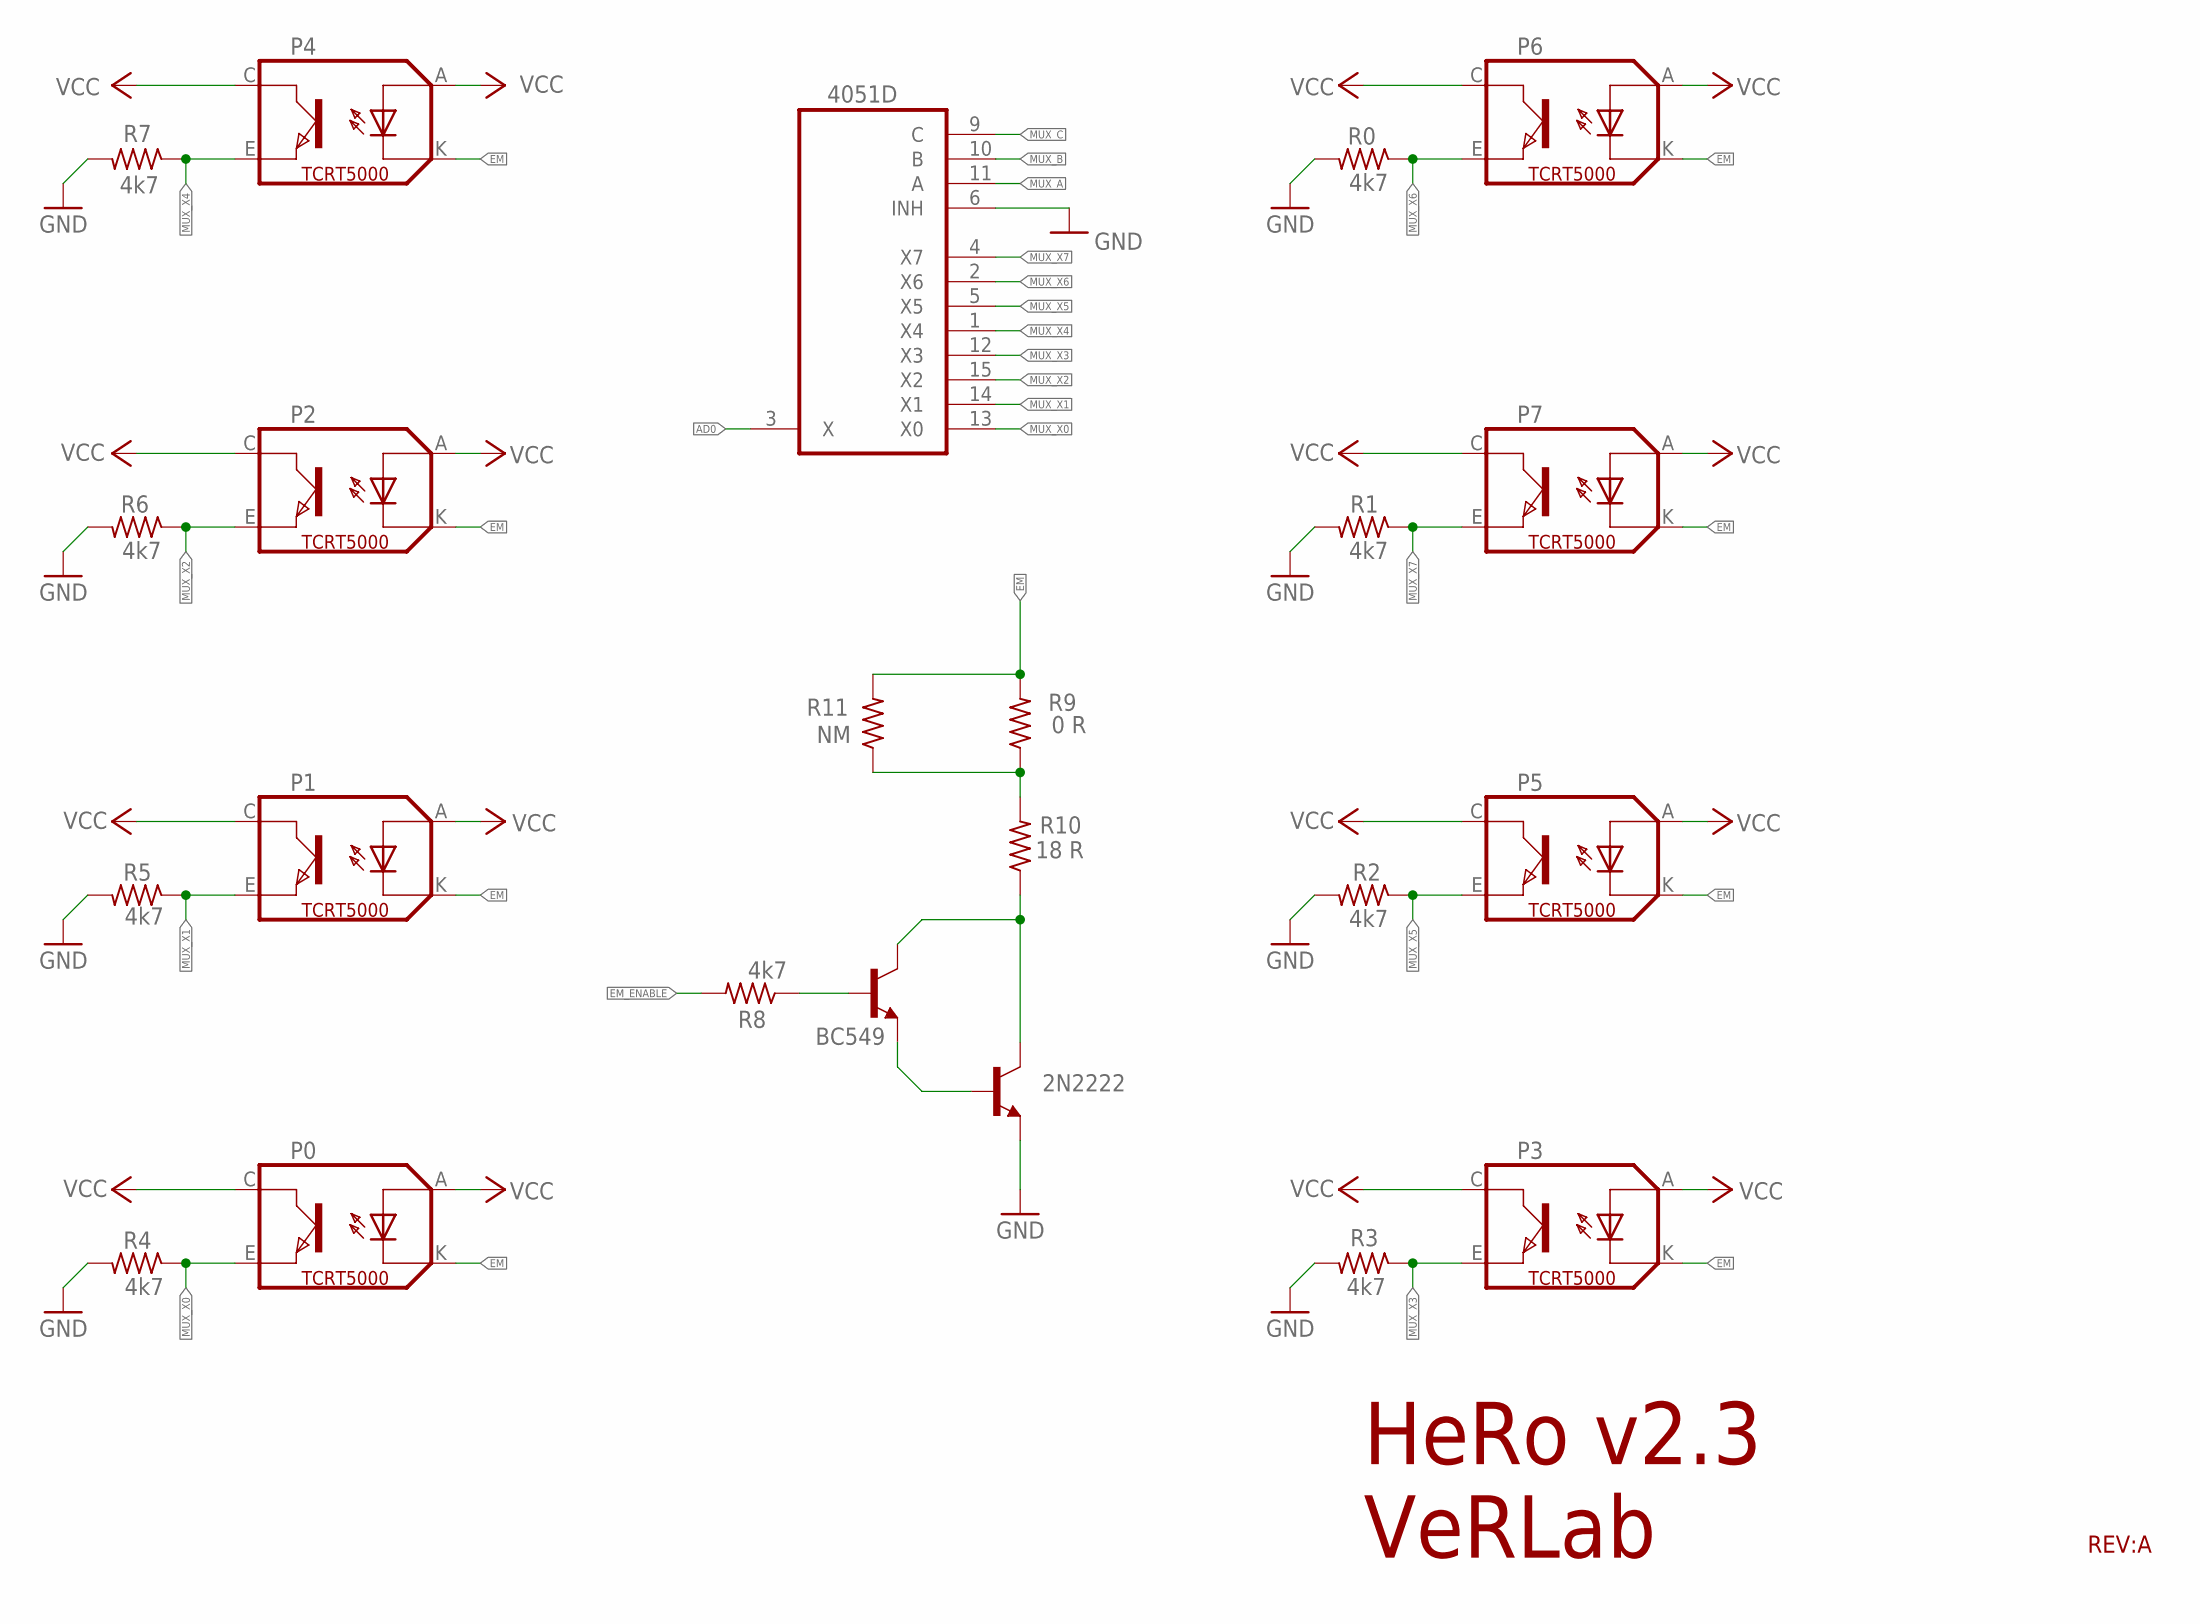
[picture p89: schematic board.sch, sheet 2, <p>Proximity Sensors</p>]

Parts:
BC549: BC549-NPN-TO92-CBE; TO92-CBE
IC2: 4051D; SO16
P0, P1, P2, P3, P4, P5, P6, P7: TCRT5000
R0, R1, R2, R3, R4, R5, R6, R7: 4k7; M0805
R8: 4k7; R0805
R9: 0 R; R0805
R10: 18 R; R0805
R11: NM; R0805
T5: 2N2222; TO92-EBC-OVAL

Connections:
AD0: IC2.3 (X); also elsewhere on the board
EM: P0.K (CATHODE), P1.K (CATHODE), P2.K (CATHODE), P3.K (CATHODE), P4.K (CATHODE), P5.K (CATHODE), P6.K (CATHODE), P7.K (CATHODE), R9.2, R11.2
EM_ENABLE: R8.2; also elsewhere on the board
EM_ENABLE_RES: BC549.B, R8.1
GND: IC2.6 (INH), IC2.8 (GND), R0.2, R1.2, R2.2, R3.2, R4.2, R5.2, R6.2, R7.2, T5.E; also elsewhere on the board
MUX_A: IC2.11 (A); also elsewhere on the board
MUX_B: IC2.10 (B); also elsewhere on the board
MUX_C: IC2.9 (C); also elsewhere on the board
MUX_X0: IC2.13 (X0), P0.E (EMITTER), R4.1
MUX_X1: IC2.14 (X1), P1.E (EMITTER), R5.1
MUX_X2: IC2.15 (X2), P2.E (EMITTER), R6.1
MUX_X3: IC2.12 (X3), P3.E (EMITTER), R3.1
MUX_X4: IC2.1 (X4), P4.E (EMITTER), R7.1
MUX_X5: IC2.5 (X5), P5.E (EMITTER), R2.1
MUX_X6: IC2.2 (X6), P6.E (EMITTER), R0.1
MUX_X7: IC2.4 (X7), P7.E (EMITTER), R1.1
unnamed: R9.1, R10.2, R11.1
unnamed: BC549.C, R10.1, T5.C
unnamed: BC549.E, T5.B
VCC: IC2.16 (VCC), P0.A (ANODE), P0.C (COLLECTOR), P1.A (ANODE), P1.C (COLLECTOR), P2.A (ANODE), P2.C (COLLECTOR), P3.A (ANODE), P3.C (COLLECTOR), P4.A (ANODE), P4.C (COLLECTOR), P5.A (ANODE), P5.C (COLLECTOR), P6.A (ANODE), P6.C (COLLECTOR), P7.A (ANODE), P7.C (COLLECTOR); also elsewhere on the board
VEE: IC2.7 (VEE)

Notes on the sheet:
HeRo v2.3 VeRLab
REV:A

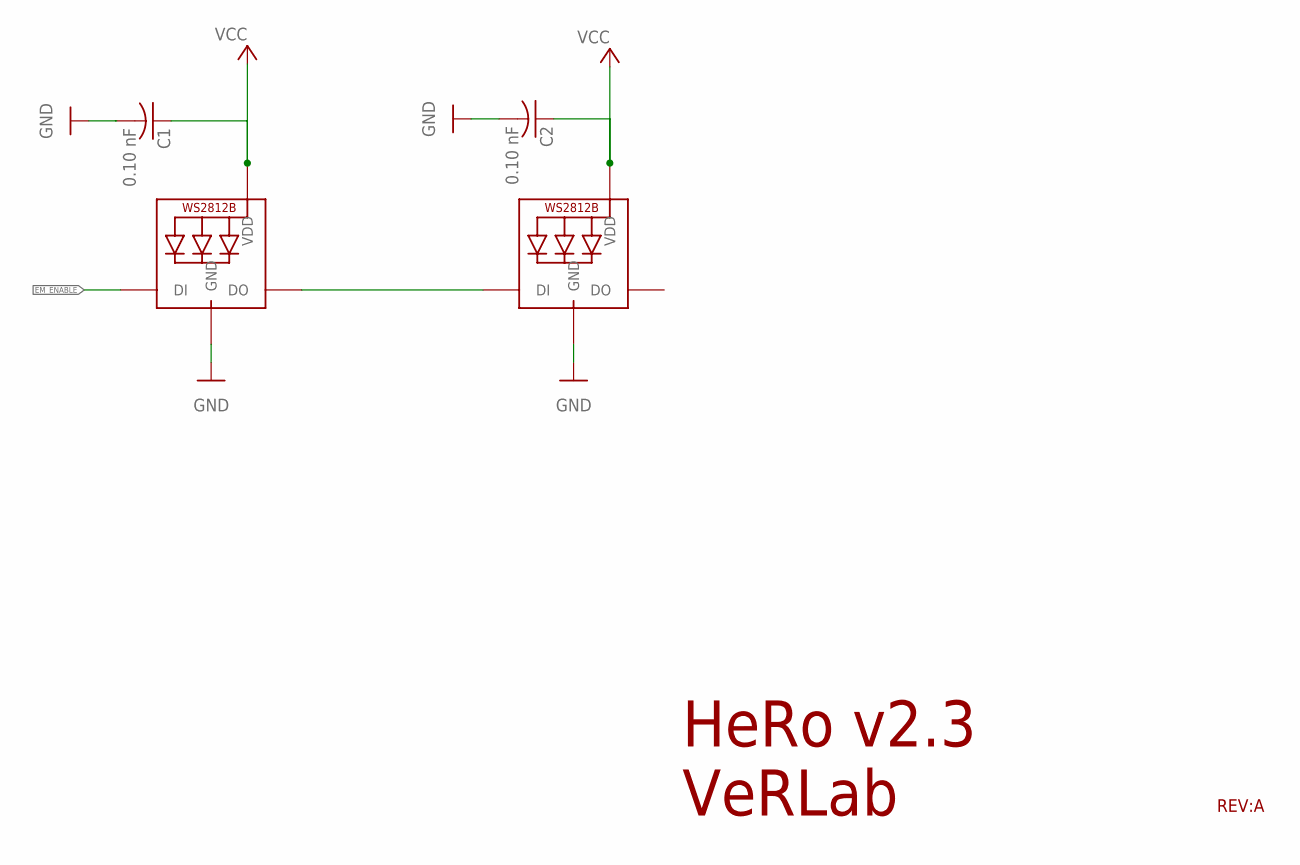
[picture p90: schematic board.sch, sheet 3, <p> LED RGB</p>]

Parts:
C1, C2: 0.10 nF; C0603
LED3, LED4: WS2812B5050; WS2812B

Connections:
EM_ENABLE: LED3.4-DIN (DI); also elsewhere on the board
GND: C1.2, C2.2, LED3.3-GND (GND), LED4.3-GND (GND); also elsewhere on the board
VCC: C1.1, C2.1, LED3.1-VDD (VDD), LED4.1-VDD (VDD); also elsewhere on the board
WS_OUT: LED3.2-DOUT (DO), LED4.4-DIN (DI)

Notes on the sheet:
HeRo v2.3 VeRLab
REV:A

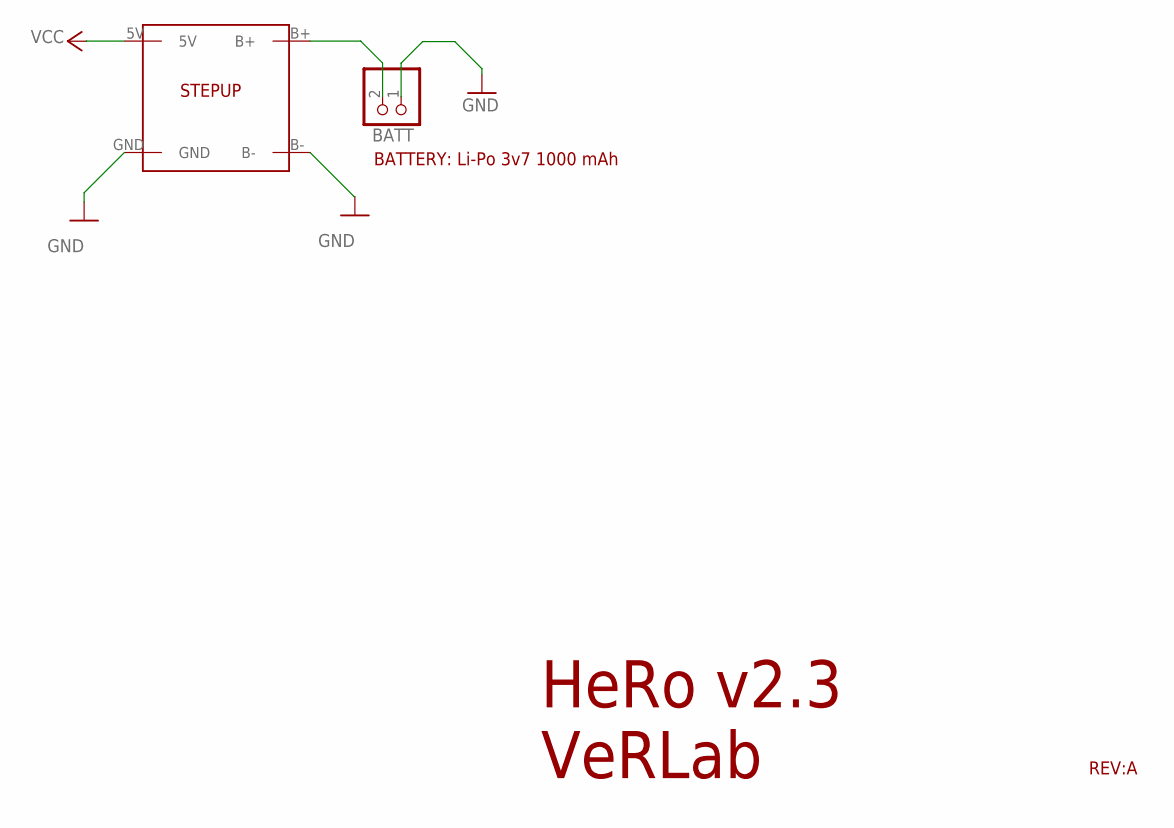
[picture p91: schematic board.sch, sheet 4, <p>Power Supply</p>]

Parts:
BATT: PINHD-1X2; 1X02
OS1: STEPUP

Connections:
B+: BATT.2, OS1.B+
GND: BATT.1, OS1.B-, OS1.GND; also elsewhere on the board
VCC: OS1.5V; also elsewhere on the board

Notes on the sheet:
HeRo v2.3 VeRLab
BATTERY: Li-Po 3v7 1000 mAh
REV:A



Board: 2 copper layers, 61.1 x 61.1 mm, 35 parts (18 on the bottom side), 30 nets.

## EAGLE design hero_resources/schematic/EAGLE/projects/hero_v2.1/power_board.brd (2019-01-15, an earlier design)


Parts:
B+: SMD2; SMD1,27-2,54
B-: SMD2; SMD1,27-2,54
GND: SMD2; SMD1,27-2,54
SWITCH: SJ2WW; SJ_2W
TP+: SMD2; SMD1,27-2,54
TP-: SMD2; SMD1,27-2,54
VCC: SMD2; SMD1,27-2,54

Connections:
unnamed: B-.1, SWITCH.2
unnamed: GND.1, SWITCH.1
unnamed: B+.1, TP+.1, VCC.1
unnamed: SWITCH.3, TP-.1


Board: 2 copper layers, 19.0 x 19.0 mm, 7 parts (0 on the bottom side), 4 nets.

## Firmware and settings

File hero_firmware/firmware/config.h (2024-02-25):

/*
  ******************************************************************************
                      H E R O   F I R M W A R E
  ******************************************************************************
  Paulo Rezeck        <rezeck@dcc.ufmg.br>
  Mauricio Ferrari    <mauferrari@dcc.ufmg.br>
  Hector Azpurua      <hectorxxx@gmail.com>


                Computer Vision and Robotics Lab (VeRLab)
               Universidade Federal de Minas Gerais - Brazil
  ******************************************************************************
  Copyright (c) 2021 Paulo Rezeck.  All right reserved.
  This library is free software; you can redistribute it and/or
  modify it under the terms of the GNU Lesser General Public
  License as published by the Free Software Foundation; either
  version 2.1 of the License, or (at your option) any later version.
  This library is distributed in the hope that it will be useful,
  but WITHOUT ANY WARRANTY; without even the implied warranty of
  MERCHANTABILITY or FITNESS FOR A PARTICULAR PURPOSE.  See the GNU
  Lesser General Public License for more details.
  You should have received a copy of the GNU Lesser General Public
  License along with this library; if not, write to the Free Software
  Foundation, Inc., 51 Franklin St, Fifth Floor, Boston, MA  02110-1301  USA
  ******************************************************************************/

#ifndef __CONFIG_H__
#define __CONFIG_H__

/* Version Configuration */
#define CONFIG_VERSION "v2.3"
#define HARDWARE_VERSION "v2.5"
#define FIRMWARE_VERSION "v3.8"

/*Robot name */
#define ROBOT_NAME "/hero_"
#define ROBOT_ID "0"

/* WIFI Configuration - use web configuration */
#define ROS_MASTER_IP "10.42.0.1" /* ROS Master IP - Config as a hotspot by default */
#define WIFI_SSID "hero_network"  /* Network name */
#define WIFI_PASSWD "s3cr3tp4ss"  /* Network password */
#define ROS_MASTER_PORT 11411     /* ROS Port */
bool default_config = true;

/* Firmware Configuration */
#define DEBUG true            /* Debug mode */
#define DEBUG_RATE 1          /* Default debug frequency */
#define SYNC_RATE 20          /* Default loop frequency */
#define MAX_BUFFER_SIZE 100   /* Max debug string buffer */
#define WIFI_CONNECT_LOOP 500 /* Time sleep when trying to connect the WIFI to an AP */
int config_mode = 0;          /* If you cover all the IR sensors with the hand, the robot start as a config mode accessed by AP mode*/

/* Robot Configuration */
#define ROBOT_DIAMETER 0.07367f                       /* Robot footprint diameter (m)*/
#define WHEEL_DIAMETER 0.0492f                        /* Wheel diameter in m. */
#define WHEEL_SEPARATION 0.063f                       /* Separation between wheels (m) */
#define WHEEL_CIRCUMFERENCE ((WHEEL_DIAMETER * M_PI)) /* Wheel circumference (meters). */
#define MOT_STEP_DIST (WHEEL_CIRCUMFERENCE / 288.0f)  /* Distance for each motor step (meters); a complete turn is 288 steps (0.000535598 meters per step (m/steps)). */
#define MAX_LINEAR_VEL 0.20                          /* max linear speed 25 m/s */
#define MAX_ANGULAR_VEL 8.0                          /* Max angular speed 0.08 rad/s */

/* Encoder Configuration */
#define ENC_A_LEFT 14           /* PIN D2 */
#define ENC_B_LEFT 4            /* PIN D5 */
#define ENC_A_RIGHT 10          /* PIN SD3 */
#define ENC_B_RIGHT 5           /* PIN D1 */
#define ENCODER_SPEED_GAIN 0.06 /* Encoder filter */
#define ENCODER_SPEED_GAIN_AGGRESSIVE 1.0

/* Motor Configuration */
#define MOTOR_RIGHT 16            /* PIN D3 */
#define MOTOR_LEFT 0              /* PIN D0 */
#define MOTOR_RIGHT_HALT_PWM 1500 /* PWM Range 1000-2000*/
#define MOTOR_LEFT_HALT_PWM 1500  /* PWM Range 1000-2000*/
#define MOTOR_STIFFNESS 1         /* Apply stiffness to the motor movement */
#define MOTOR_PWM_SUBSCRIBER_ENABLE true

/* Laser Configuration */
#define MUX_A 15                                             /* PIN D8 */
#define MUX_B 13                                             /* PIN D7 */
#define MUX_C 12                                             /* PIN D6 */
#define MUX_EN 2                                             /* PIN D4 */
#define TOUCH_THRESHOLD 450                                  /* If sensor readings reach 900 than we assume a touch sensor */
const int real_pos[8] = { 0, 1, 2, 7, 3, 6, 4, 5 };          /* Sort proximity sensors*/
const int real_pos_inter[8] = { 0, 2, 4, 14, 6, 12, 8, 10 }; /* Sort proximity sensors*/

/* I2C Configuration */
#define I2C_SDA 3 /* PIN RX */
#define I2C_SCL 1 /* PIN TX */


/* IMU Enable */
#define IMU_ENABLE false /* Enable or disable IMU */
#define XGYRO_OFFSET 220 /* Supply your own gyro offsets here, scaled for min sensitivity */
#define YGYRO_OFFSET 76
#define ZGYRO_OFFSET -85
#define ZACC_OFFSET 1788


/* Addressable LED WS2812b */
#define PIXEL_COUNT 7        /* NUMBER OF LED */
#define COLOR_SATURATION 255 /* MAX SATURATION COLOR */


/* PID Control */
#define DEFAULT_KP 1200                    /* Default proportional term */
#define DEFAULT_KI 7.5                     /* Default integrative term */
#define DEFAULT_KD 3.5                     /* Default derivative term */
#define OUTPUT_LIMIT 1000                  /* Max output limit */
#define SAMPLE_TIME 50000                  /* Sample time in us*/
#define SOME_OVERSHOOT_RULE_P 1.5          //3.2           /* Using some-overshot rule */
#define SOME_OVERSHOOT_RULE_I 1.0          //0.07
#define SOME_OVERSHOOT_RULE_D 0.08         //0.002
#define TUNING_SUCCESSED_THRESHOLD_MIN 200 /* Sanity-test to decide if tuning process was ok; looks only the proportional term */
#define TUNING_SUCCESSED_THRESHOLD_MAX 2700
//#define MEM_INIT_POS_PID 300/

/* Autotuner */
#define TUNE_STEP 40                /* How far above and below the starting value will the output step? */
#define TUNE_NOISE 0.001            /* The autotune will ignore signal chatter smaller than this value this should be accurately set */
#define TUNE_LOOK_BACK 3            /* How far (seconds) back are we looking to identify peaks */
#define TUNE_STEADY_STATE_TIME 8000 /* Steady state time (ms) before pertubation */
#define TUNE_STEADY_STATE 80        //120          /* Steady state PWM to start Autotune 0 - 100 should be ok*/

struct PID_CONFIG {
  float lkp;
  float lki;
  float lkd;
  float rkp;
  float rki;
  float rkd;
} configurationPID = {
  // The default values
  -1,
  -1,
  -1,
  -1,
  -1,
  -1
};

struct DATA {
  uint robot_id;
  char robot_desc[20];
  char ros_master_address[20];
  char wifi_ssid[20];
  char wifi_pass[20];
} configurationData = {
  // The default values
  0,
  "",
  "",
  "",
  ""
};

struct MOTOR_P {
  int leftMotorDeadzone;
  int rightMotorDeadzone;
} motorData = {
  // The default values
  -1,
  -1
};


struct IR_CALIB {
  float alpha[8];
} irCalib = {
  // The default values
  { 0.5, 0.5, 0.5, 0.5, 0.5, 0.5, 0.5, 0.5 }
};


#endif  // ___CONFIG_H__

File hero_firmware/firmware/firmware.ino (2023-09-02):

/*
  ******************************************************************************
                      H E R O   F I R M W A R E
  ******************************************************************************
  Paulo Rezeck        <rezeck@dcc.ufmg.br>
  Mauricio Ferrari    <mauferrari@dcc.ufmg.br>
  Hector Azpurua      <hectorxxx@gmail.com>


                Computer Vision and Robotics Lab (VeRLab)
               Universidade Federal de Minas Gerais - Brazil
  ******************************************************************************
  Copyright (c) 2021 Paulo Rezeck.  All right reserved.
  This library is free software; you can redistribute it and/or
  modify it under the terms of the GNU Lesser General Public
  License as published by the Free Software Foundation; either
  version 2.1 of the License, or (at your option) any later version.
  This library is distributed in the hope that it will be useful,
  but WITHOUT ANY WARRANTY; without even the implied warranty of
  MERCHANTABILITY or FITNESS FOR A PARTICULAR PURPOSE.  See the GNU
  Lesser General Public License for more details.
  You should have received a copy of the GNU Lesser General Public
  License along with this library; if not, write to the Free Software
  Foundation, Inc., 51 Franklin St, Fifth Floor, Boston, MA  02110-1301  USA
  ******************************************************************************/

/* ESP Library */
#include <ESP8266WiFi.h>

/* ROS Library */
#define ROSSERIAL_ARDUINO_TCP
#include <ros.h>

/* Libraries */
#include "config.h"

#include "LEDStatus.h"
LEDStatus ledStatus(20);

#include "WebConfig.h"
WebConfig webConfig(4);

#include "ROSHandle.h"
ROSHandle rosHandle(SYNC_RATE, 1);

#include "RangeSensor.h"
RangeSensor rangeSensor(10);

#include "WheelEncoder.h"
WheelEncoder wheelEncoder(30);

#include "IMUSensor.h"
IMUSensor imuSensor(20);

#include "Odometry.h"
Odometry odometry(30);

#include "MotorDriver.h"
MotorDriver motorDriver(20);

#include "PositionControl.h"
PositionControl positionControl(20);

#include "VelocityControl.h"
VelocityControl velocityControl(20);

#include "RandomWalk.h"
RandomWalkDemo randomWalkDemo(5);

/* Main Setup */
void setup() {
  /* Stopping Motors */
  pinMode(MOTOR_RIGHT, OUTPUT);
  pinMode(MOTOR_LEFT, OUTPUT);
  digitalWrite(MOTOR_RIGHT, LOW);
  digitalWrite(MOTOR_LEFT, LOW);
  /* Setup laser Readings */
  rangeSensor.connect();
  /* Cover all the range sensor to enable web config mode */
  config_mode = rangeSensor.configModeCheck();
  /* Clean status led */
  ledStatus.reset();

  switch (config_mode) {
    case 17:  // RandomWalk demo
      {
        // Disable Wi-Fi
        WiFi.mode(WIFI_OFF);
        // Blink blue led
        ledStatus.welcome(*ledStatus.blue, 100);
        // Setup wheel encoder sensor
        wheelEncoder.init();
        // Setup motor driver
        motorDriver.init();
        // Setup range sensor
        rangeSensor.init();
        // Setup velocity controller
        velocityControl.init(motorDriver, wheelEncoder);
        // Setup random walk controller
        randomWalkDemo.init(velocityControl, rangeSensor, ledStatus);
        break;
      }

    case 255:
      {
        // Create an AP that enables the user to setup some parameters of the robot. See config_via_wifi.h.
        webConfig.init(ledStatus);
        break;
      }

    default:
      {
        // Setup ROS Communication
        rosHandle.init(ledStatus);

        // Setup LED to communicate with ROS
        ledStatus.init(rosHandle.nh, rosHandle.heroName);
        // Setup range sensor to communicate with ROS
        rangeSensor.init(rosHandle.nh, rosHandle.heroName);
        // Setup imu sensor to communicate with ROS
        imuSensor.init(rosHandle.nh, rosHandle.heroName);
        // Setup wheel encoder sensor to communicate with ROS
        wheelEncoder.init(rosHandle.nh, rosHandle.heroName);

        // Compute odometry to send with ROS
#ifdef __IMU_SENSOR_H__
        odometry.init(rosHandle.nh, rosHandle.heroName, wheelEncoder, imuSensor);
#else
        odometry.init(rosHandle.nh, rosHandle.heroName, wheelEncoder);
#endif

        // Setup motors to communicate with ROS
        motorDriver.init(rosHandle.nh, rosHandle.heroName);

        // Compute position control to by receiving commands from ROS
        positionControl.init(rosHandle.nh, rosHandle.heroName, motorDriver, wheelEncoder);
        // Compute velocity control to by receiving commands from ROS
        velocityControl.init(rosHandle.nh, rosHandle.heroName, motorDriver, wheelEncoder);

        ledStatus.welcome(*ledStatus.cyan, 100);
        break;
      }
  }
}


/* Main loop */
void loop() {

  switch (config_mode) {
    case 17:  // Random Walk demo
      {
        // random walk controller update
        randomWalkDemo.update(5);
        // led status update
        ledStatus.update(2);
        // velocity controller update
        velocityControl.update(50);
        delayMicroseconds(50000);
        break;
      }

    case 255:  // Web Configuration Mode
      {
        webConfig.update();
        break;
      }

    default:  // ROS Mode
      {
        if (rosHandle.connected()) {
          /* Get data from sensor and send it to ROS */
          motorDriver.update(10);
          imuSensor.update(30);
          ledStatus.update(2);
          rangeSensor.update(5);
          odometry.update(30);
          wheelEncoder.update(30);
          positionControl.update(50);
          velocityControl.update(50);

          rosHandle.sync();
        } else {
          // ROS Mode with delay
          delayMicroseconds(50000);
          rosHandle.sync();
        }
        break;
      }
  }
}

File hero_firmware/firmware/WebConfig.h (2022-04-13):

/*
  ******************************************************************************
                      H E R O   F I R M W A R E
  ******************************************************************************
  Paulo Rezeck        <rezeck@dcc.ufmg.br>
  Mauricio Ferrari    <mauferrari@dcc.ufmg.br>
  Hector Azpurua      <hectorxxx@gmail.com>


                Computer Vision and Robotics Lab (VeRLab)
               Universidade Federal de Minas Gerais - Brazil
  ******************************************************************************
  Copyright (c) 2021 Paulo Rezeck.  All right reserved.
  This library is free software; you can redistribute it and/or
  modify it under the terms of the GNU Lesser General Public
  License as published by the Free Software Foundation; either
  version 2.1 of the License, or (at your option) any later version.
  This library is distributed in the hope that it will be useful,
  but WITHOUT ANY WARRANTY; without even the implied warranty of
  MERCHANTABILITY or FITNESS FOR A PARTICULAR PURPOSE.  See the GNU
  Lesser General Public License for more details.
  You should have received a copy of the GNU Lesser General Public
  License along with this library; if not, write to the Free Software
  Foundation, Inc., 51 Franklin St, Fifth Floor, Boston, MA  02110-1301  USA
  ******************************************************************************/

#ifndef __WEB_CONFIG_H__
#define __WEB_CONFIG_H__

#include <EEPROM.h>
#include <ESP8266WiFi.h>
#include <WiFiClient.h>
#include <ESP8266WebServer.h>

#include "LEDStatus.h"

// between 4 and 4096bytes
#define MEM_ALOC_SIZE 512
#define MEM_INIT_POS 0

const char WiFiAPPSK[] = "s3cr3tp4ss";
/* GZip Encoded css file and icon */
const char css_gzip[] = {0x1F, 0x8B, 0x08, 0x08, 0xF2, 0xCE, 0xD8, 0x60, 0x00, 0x03, 0x74, 0x65, 0x73, 0x74, 0x2E, 0x63, 0x73, 0x73, 0x00, 0xBD, 0x59, 0x5B, 0x8F, 0xDB, 0xB8, 0x15, 0x7E, 0xCE, 0xCF, 0xD8, 0x04, 0x8B, 0x8C, 0x03, 0x49, 0xAB, 0x8B, 0x65, 0x7B, 0x24, 0x04, 0xE8, 0x76, 0xBB, 0x6D, 0xF7, 0x61, 0xFB, 0xD0, 0xEC, 0x02, 0x05, 0x9A, 0x3E, 0x50, 0x22, 0x65, 0x2B, 0x23, 0x4B, 0x82, 0x24, 0xCF, 0xD8, 0x11, 0xFC, 0xDF, 0x7B, 0x78, 0x93, 0x49, 0x89, 0xF2, 0xD8, 0x4D, 0xDB, 0x99, 0x64, 0x6C, 0x91, 0xE7, 0xC6, 0xC3, 0xEF, 0x5C, 0x48, 0xED, 0x7C, 0x6B, 0xB7, 0xB4, 0x76, 0x2B, 0xAB, 0xB6, 0x0E, 0x45, 0xFF, 0x66, 0x8F, 0x9A, 0x6D, 0x5E, 0xDA, 0x5D, 0x55, 0x47, 0xEE, 0x79, 0x27, 0xE7, 0x0A, 0x94, 0x90, 0xCB, 0x64, 0x52, 0x75, 0x5D, 0xB5, 0x8F, 0x9C, 0xB0, 0x21, 0xFB, 0x73, 0x72, 0x80, 0x87, 0xD2, 0xDA, 0x35, 0x56, 0x5E, 0xD6, 0x87, 0xAE, 0x7F, 0x53, 0x3D, 0x93, 0x26, 0x2B, 0xAA, 0x97, 0xE8, 0x39, 0x6F, 0xF3, 0xA4, 0x20, 0x67, 0x98, 0xD2, 0x64, 0x0B, 0x76, 0x8F, 0x72, 0x3B, 0x49, 0x57, 0x5A, 0xF9, 0x7E, 0xDB, 0xBF, 0x01, 0xAE, 0x2E, 0x4F, 0x51, 0x61, 0xA3, 0x22, 0xDF, 0x96, 0xD1, 0x3E, 0xC7, 0x18, 0x78, 0xE9, 0xBC, 0x5D, 0x37, 0x39, 0xB0, 0x9E, 0x2C, 0xF6, 0xF0, 0x82, 0x9A, 0x32, 0x2F, 0x81, 0x21, 0x41, 0xE9, 0xD3, 0xB6, 0xA9, 0x0E, 0x25, 0xB6, 0x1B, 0x52, 0x13, 0xD4, 0x45, 0xFC, 0xC3, 0x3E, 0x9E, 0x3F, 0x58, 0x51, 0x84, 0xB2, 0x8E, 0x34, 0xF0, 0x99, 0x90, 0xAC, 0x6A, 0x08, 0x90, 0x57, 0x47, 0xBB, 0xCD, 0xBF, 0x02, 0x6B, 0x94, 0x54, 0x0D, 0x26, 0x0D, 0xD8, 0x71, 0x3C, 0x67, 0x55, 0x05, 0x64, 0xFD, 0x1B, 0x9C, 0xB7, 0x75, 0x81, 0x4E, 0x51, 0x52, 0x54, 0xE9, 0xD3, 0xD9, 0x29, 0xF2, 0xB6, 0xB3, 0xF3, 0xB2, 0xC8, 0x4B, 0x62, 0xE7, 0x1D, 0xD9, 0x4B, 0x07, 0x48, 0x32, 0x31, 0xC5, 0xA9, 0x93, 0x0A, 0x9F, 0xE4, 0xE2, 0x22, 0x37, 0x7E, 0x93, 0x55, 0x65, 0x67, 0x67, 0x68, 0x9F, 0x17, 0xA7, 0xC8, 0x46, 0x75, 0x5D, 0x10, 0xBB, 0x3D, 0xB5, 0x54, 0xCA, 0x1F, 0x81, 0xEB, 0xE9, 0x57, 0x94, 0x7E, 0x62, 0x8F, 0x7F, 0x06, 0x3A, 0xEB, 0xF3, 0xDB, 0x4F, 0x64, 0x5B, 0x91, 0xDF, 0x7F, 0xF9, 0xFC, 0xD6, 0xFA, 0x7B, 0x05, 0xAE, 0xA9, 0x60, 0xE8, 0xAF, 0xA4, 0x78, 0x26, 0xD4, 0x1B, 0x7F, 0x23, 0x07, 0x02, 0x13, 0x3F, 0x36, 0x39, 0x2A, 0xAC, 0x16, 0x95, 0xAD, 0xDD, 0x92, 0x26, 0xCF, 0x80, 0xE4, 0x47, 0x2A, 0xF7, 0xA7, 0xAA, 0xA8, 0x9A, 0x9F, 0xF7, 0xD5, 0x97, 0x1C, 0x88, 0x06, 0x49, 0x93, 0x81, 0x4F, 0xA7, 0x7D, 0x52, 0x15, 0x9F, 0xDF, 0xC6, 0xCC, 0x32, 0x70, 0x02, 0x61, 0xCE, 0xE7, 0x8F, 0x2F, 0x24, 0xDF, 0xEE, 0xBA, 0x68, 0xE9, 0xBA, 0x31, 0x5B, 0xD3, 0x8E, 0x3F, 0x7B, 0x4E, 0x18, 0xA7, 0x54, 0x7C, 0xF4, 0xCE, 0xF7, 0xFC, 0xD0, 0x7F, 0x8C, 0x3B, 0x72, 0xEC, 0xC4, 0xE6, 0x14, 0x24, 0xEB, 0x62, 0xC5, 0xFF, 0x82, 0x30, 0xCB, 0xB2, 0x01, 0x32, 0xBD, 0xEA, 0x85, 0xBC, 0xDC, 0x81, 0xD9, 0x9D, 0xA6, 0x30, 0x9C, 0x28, 0xF4, 0x85, 0x42, 0x41, 0x7D, 0x6E, 0xF7, 0xA8, 0x28, 0xFA, 0x8B, 0xCD, 0x1B, 0xF7, 0xFB, 0x33, 0xEA, 0x85, 0x2E, 0xD7, 0x5D, 0x27, 0x59, 0xC6, 0x8D, 0xC2, 0x24, 0xAD, 0x1A, 0xD4, 0xE5, 0x55, 0x19, 0x95, 0x55, 0x49, 0xA6, 0x96, 0x75, 0x0D, 0xB8, 0xAE, 0x46, 0x0D, 0x29, 0xBB, 0x18, 0xF4, 0x27, 0x4F, 0x79, 0x67, 0x8F, 0x38, 0xED, 0xF6, 0x29, 0xAF, 0xA3, 0x2A, 0xF9, 0x42, 0xD2, 0xAE, 0x3D, 0xA3, 0x68, 0x47, 0x61, 0x7C, 0x51, 0x16, 0xAE, 0x92, 0x60, 0xA2, 0x0C, 0x14, 0x90, 0x86, 0xAE, 0xE1, 0x4C, 0x11, 0x2C, 0x50, 0xD5, 0x76,
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

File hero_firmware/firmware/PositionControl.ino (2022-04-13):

/*
  ******************************************************************************
                      H E R O   F I R M W A R E
  ******************************************************************************
  Paulo Rezeck        <rezeck@dcc.ufmg.br>
  Mauricio Ferrari    <mauferrari@dcc.ufmg.br>
  Hector Azpurua      <hectorxxx@gmail.com>


                Computer Vision and Robotics Lab (VeRLab)
               Universidade Federal de Minas Gerais - Brazil
  ******************************************************************************
  Copyright (c) 2021 Paulo Rezeck.  All right reserved.
  This library is free software; you can redistribute it and/or
  modify it under the terms of the GNU Lesser General Public
  License as published by the Free Software Foundation; either
  version 2.1 of the License, or (at your option) any later version.
  This library is distributed in the hope that it will be useful,
  but WITHOUT ANY WARRANTY; without even the implied warranty of
  MERCHANTABILITY or FITNESS FOR A PARTICULAR PURPOSE.  See the GNU
  Lesser General Public License for more details.
  You should have received a copy of the GNU Lesser General Public
  License along with this library; if not, write to the Free Software
  Foundation, Inc., 51 Franklin St, Fifth Floor, Boston, MA  02110-1301  USA
  ******************************************************************************/

#include "PositionControl.h"

PositionControl::PositionControl(unsigned long rate) {
  this->timer = millis();
  this->setRate(rate);

  /* Setup left Motor PID */
  this->leftMotorPID = new PID (&this->leftMotorInput, &this->leftMotorOutput, &this->leftMotorSetpoint, 5.0, 9.0, 0.1, 0, REVERSE); /* Motor PID */
  this->leftMotorPID->SetMode(AUTOMATIC);
  this->leftMotorPID->SetOutputLimits(-output_lim, output_lim);       /* Max output limit for left motor */
  this->leftMotorPID->SetSampleTime(sample_time);                     /* 10 microseconds */

  /* Setup autotuner for PID */
  this->leftMotorPIDTune = new PID_ATune(&this->leftMotorInput, &this->leftMotorOutput);    /* PID autotuner */
  this->leftMotorPIDTune->SetControlType(PID_ATune::NO_OVERSHOOT_PID);    /* Set control type for autotuner */
  this->leftMotorPIDTune->SetNoiseBand(TUNE_NOISE);                         /* The autotune will ignore signal chatter smaller than this value this should be accurately set */
  this->leftMotorPIDTune->SetOutputStep(TUNE_STEP);                         /* How far above and below the starting value will the output step? */
  this->leftMotorPIDTune->SetLookbackSec((int)TUNE_LOOK_BACK);              /* How far back are we looking to identify peaks */

  /* Setup right Motor PID */
  this->rightMotorPID = new PID (&this->rightMotorInput, &this->rightMotorOutput, &this->rightMotorSetpoint, 5.0, 9.0, 0.1, 0, DIRECT); /* Motor PID */
  this->rightMotorPID->SetMode(AUTOMATIC);
  this->rightMotorPID->SetOutputLimits(-output_lim, output_lim);       /* Max output limit for left motor */
  this->rightMotorPID->SetSampleTime(sample_time);                     /* 10 microseconds */

  this->rightMotorPIDTune = new PID_ATune(&this->rightMotorInput, &this->rightMotorOutput);    /* PID autotuner */
  this->rightMotorPIDTune->SetControlType(PID_ATune::NO_OVERSHOOT_PID);
  this->rightMotorPIDTune->SetNoiseBand(TUNE_NOISE);                        /* The autotune will ignore signal chatter smaller than this value this should be accurately set */
  this->rightMotorPIDTune->SetOutputStep(TUNE_STEP);                        /* How far above and below the starting value will the output step? */
  this->rightMotorPIDTune->SetLookbackSec((int)TUNE_LOOK_BACK);             /* How far back are we looking to identify peaks */

  EEPROM.begin(MEM_ALOC_SIZE);
  EEPROM.get(MEM_INIT_POS_PID_POSITION, configPosPID);
  EEPROM.end();

  if (configPosPID.lkp > 0) {
    this->leftMotorPID->SetTunings(configPosPID.lkp, configPosPID.lki, configPosPID.lkd);
  }

  if (configPosPID.rkp > 0) {
    this->rightMotorPID->SetTunings(configPosPID.rkp, configPosPID.rki, configPosPID.rkd);
  }
}

void PositionControl::init(ros::NodeHandle &nh, String heroName, MotorDriver& motorDriver, WheelEncoder& wheelEncoder) {
  this->motorDriver = &motorDriver;
  this->wheelEncoder = &wheelEncoder;

  this->nh_ = &nh;   /* ROS Node Handle */
  this->heroName = heroName;

  /* Address command velocity-position subscribe */
  this->cmdvelTopic = this->heroName + String("/position_controller/cmd_vel");                          /* Update topic name */
  this->cmdvelSub = new ros::Subscriber<geometry_msgs::Twist, PositionControl>(this->cmdvelTopic.c_str(), &PositionControl::cmdvelCallback, this);     /* Instantiate subscriber */
  this->nh_->subscribe(*this->cmdvelSub);      /* Address Command Vel */

  /* Address set PID motors service */
  this->setPIDTopic = this->heroName + String("/position_controller/pid_parameters");                                                                                                 /* Update service name */
  this->setPIDService = new ros::ServiceServer<hero_common::SetPID::Request, hero_common::SetPID::Response, PositionControl>(this->setPIDTopic.c_str(), &PositionControl::setPIDCallback, this);               /* Instantiate service */
  this->nh_->advertiseService(*this->setPIDService);                                                                                                                          /* Address fix motors service */

  /* Address PID calibration service */
  this->pidCalibrationTopic = this->heroName + String("/position_controller/pid_calibration");                                                                                                     /* Update service name */
  this->pidCalibrationService = new ros::ServiceServer<std_srvs::Trigger::Request, std_srvs::Trigger::Response, PositionControl>(this->pidCalibrationTopic.c_str(), &PositionControl::pidCalibrationCallback, this);    /* Instantiate service */
  this->nh_->advertiseService(*this->pidCalibrationService);
}


void PositionControl::setRate(unsigned long rate) {
  this->rate = rate;
}

void PositionControl::update() {
  this->update(this->rate);
}
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

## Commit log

2017-03-06 Update ros serial driver to use python node
2017-03-07 Working on reader/write mode with interrupt signal
2017-03-08 Fix interrupt mode to receive and send messages
2017-03-08 Created ros driver to manager the robots
2017-03-09 Updated servo motor neutral position
2017-03-18 added cad file of robot
    [swarm_robot.fcstd]
2017-03-20 Rename launch and change neutral position of the wheels.
2017-03-20 Update servo neutral position
2017-03-20 Adjust to use microseconds write on servo
2017-03-24 Implement mode to (simutaneous) receive data from Sensors and control the robot.
2017-04-13 Create WifiHardware to comunicate via wifi with ros using nodemcu device
2017-05-26 Add IR sensor
2017-05-27 Simplified arduino code, added twist messages, simple config in main cpp file
2017-05-30 added camera and tracker launch file
2017-05-30 added camera parameters in file
    [camera_calibration.yaml]
2017-05-30 Added calibration file from arena
    [camera_calibration.yaml]
2017-05-30 updated track launch file
2017-05-31 updated camera launch
2018-05-04 Added 3d printer parts
    [base.stl, base_middle.stl, cover.stl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]
2018-05-04 Added nodemcu and jst pin 3d model
    [jst_2_pin_90.stl]
2018-05-04 Added tcrt5000 3d model
    [jst_2_pin_90.stl, tcrt5000.stl]
2018-08-21 Added new cad model
    [base.stl, base_middle.stl, battery.stl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]
2018-09-26 Add description and simulation on gazebo
    [base.stl, base_link.obj, base_middle.stl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]
2018-09-27 Added laser and multi hero launch
    [hero.xacro]
2018-10-02 Improved collision, inertial and modularization
    [common.xacro, hero.gazebo.xacro, hero.transmissions.xacro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]
2018-10-02 Fix laser noise and differential controller plugin
    [hero.gazebo.xacro, laser.gazebo.xacro]
2018-10-20 Added support to ar track alvar to provide global pose to HeRo; Not tested yet.
    [camera_calibration.yaml]
2018-10-24 Update odometry_test
2018-10-24 Added odometry test; hero compare to epuck.
2019-01-15 Added IR, IMU and Encoders tests
2019-01-15 Update firmware with IMU, Encoders, IR and LEDs
2019-01-15 Added cad and board schematic
    [board.brd, board.sch, board_chassis.f3d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]
2019-01-28 Added new 3d model; update tests; refactor sketches
    [board_chassis.stl, encoder_gear.stl, hat.stl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]
2019-04-17 Update PCB schematic; Version 2.5 not tested yet.
    [board.brd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]
2019-04-22 Fix battery connector position in board v2.5
    [board.brd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]
2019-04-24 Fix unset interruption mode to the GPIO10; Check if the esp8266 is on DIO Flash mode.
2019-04-24 Fix board v2.5 charge power led to 0805.
    [board.brd, board.sch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]
2019-04-28 Added new message types for encoder and motor; update setPID service;
2019-04-28 Update firmware to version 2.5; refactored the firmware; added webpage setup wifi; fix encoder read interruption; fix PID parameters
    [config.h, eeprom_test.ino, encoder_test.ino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]
2019-06-03 Remove PID library
2019-06-03 Fix PID library
2019-06-05 Added hero v2.5 board BOM
2019-12-12 Fix neopixel test delay
    [neopixel_test.ino]
2020-01-23 Fix some issues in these test; Add ir and neopixel test
    [neopixel_ir_test.ino, neopixel_test.ino]
2020-01-25 Added mosfet datasheet
2020-01-29 add the arduino IDE download link
2020-02-08 Update ros library; Update neopixel, ir and motor tests
2021-02-04 Improve gazebo simulation setup; add swarm arena setup;
    [arena.urdf.xacro, common.xacro, hero.gazebo.xacro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]
2021-07-15 updating 3d model parts
    [board_chassis.stl, castor_wheel.stl, chasis_b.stl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]
2022-04-13 Major Modifications
    [arena.urdf, arena.urdf.xacro, base_link.obj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]
2022-04-14 Remove ar-track-alvar dependencies
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2022-04-14 Update to use urdf instead xacro -- fix ros noetic version
2022-04-19 Update eagle projects; BOM available
    [board.brd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]
2022-04-19 Update BOM; TP4056 Optional
2022-04-20 Add last CAD model
    [board_chassis.f3d, castor_wheel.stl, chasis_b.stl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]
2022-04-20 Update PCB 2.6
    [board.brd, board.sch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]
2022-04-21 Fix castor wheel 3d printer stl
    [castor_wheel.stl]
2022-04-21 Fix motor gear 3d printer file
    [motor_gear.stl]
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2022-10-09 Update PCB to support MT3608 stepup
    [PnP_board_back.csv, PnP_board_front.csv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]
2023-01-05 Fix builtin recharger resistor wrong description #16
2023-01-07 Fix IRAM_ATTR problem with interrupts on ESP8266; Encoder Lib v1.4.3; issue #15
2023-01-07 Fix i2s.h missing issue for NeoPixelBus, esp8266 board > 2.5.0-3.1.0; issue #14
2023-01-08 Fix Encoder Lib absence of interrupt on gpio 10
2023-01-08 Fix tf name for laser frame
    [RangeSensor.ino]
2023-01-09 Fix MOSFET pinMode reset for IR sensors
    [RangeSensor.ino, ir_test.ino, neopixel_ir_test.ino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]
2023-02-09 Fix robot urdf compatibility
2023-02-13 Update firmware config file and fix bug IR sensor
    [RangeSensor.ino, config.h]
2023-02-13 Add IR calibration script #17
2023-02-13 Add IR Calibration Support 3D printer #17
    [ir_calibration_support.stl, ircal_holder.stl, ircal_plate.stl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]
2023-02-13 Fix xacro urdf remapping #18, thanks @jacobh2299
    [common.xacro]
2023-03-06 Fix incorrectlu battery connector polarity labeled on PCB #19
    [PnP_board_back.csv, PnP_board_front.csv, board.brd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]
2023-07-27 Update range sensor example
2023-08-10 Add IR calibration script
2023-08-10 Fix IR overdriver and signal to meter function
    [RangeSensor.ino]
2023-08-14 Update frame name for compability with noetic
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2023-08-26 Decrease motor stiffness param
    [config.h]
2023-09-02 Update pcb board version
    [PnP_board_back.csv, PnP_board_front.csv, board.brd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]
2023-09-02 Update docker and launch files
    [common.xacro]
2023-09-20 Add new arena environments and maps
    [arena.obj, arena.urdf]
2023-09-22 Update hero laser description to match with real robots
    [hero_laser.urdf]
2023-09-22 Remove unecessary file
    [hero_laser (copy).urdf]
2023-09-23 Reduce mesh polygon to improve gazebo performance
    [base_link.obj, hat.obj]
2023-09-24 Reduce model polygons to increase simulation performance
    [arena.obj, wheel.obj]
2023-09-25 Changing from alvartrack to apriltag camera tracker
2023-10-03 Add script to convert tag pose information to robot odometry
2023-10-08 Update camera calibration parameters
    [camera_calibration.yaml]
2023-10-08 Decrease hero simulation update rate
    [hero_light.urdf]
2023-10-08 Fix unmatching PCB board version 2.7 (issue #22)
    [PnP_board_back.csv, PnP_board_front.csv, board.brd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]
2024-02-24 Update hero tracker configuration
    [camera_calibration.yaml]
2024-02-24 Add tag to pose converter and filter
2024-02-24 Add localization filter and update rviz config
2024-02-24 Add laser enable/disable ros topics
2026-08-23 Rebuild the docs site with guided Build and Software pages.
    Replace Minima with a custom theme, local assembly figures, OpenAlex citations, and a four-step software path so the published GitHub Pages site matches the current HeRo 2.0 material.
    [castor_wheel.stl, chasis_b.stl, chassis_a.stl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]
2026-08-23 Add Genesis World next to Gazebo and document the NVIDIA GPU path.
    hero_genesis loads the official URDF and arenas with the same /hero_N topics; the software page now covers local, CUDA, and Docker GPU setups.
2026-10-17 Use xacro: prefix for property and macro in common.xacro
    Unprefixed <property> and <macro> are no longer supported by xacro in
    Noetic; hero.urdf.xacro failed with "name 'm' is not defined".
2026-10-17 Remove gazebo_ros_control from the robot descriptions
    The plugin waits in Load() for the robot_description parameter and blocks
    the world update thread, so the plugins loaded after it (diff drive, IR,
    IMU) are never initialized. No launch file starts a controller manager;
    the drive uses libgazebo_ros_diff_drive.
2026-10-17 Match the simulated IR ring to the firmware
    - 16 rays at 22.5 deg spacing, index 8 forward (max_angle = pi - 2 pi/16)
    - Range 0.0368 m to 0.2568 m as published by the firmware, Gaussian noise
    - Update rate 5 Hz as in rangeSensor.update(5)
    - Sensor pose offset removed: laser_joint already sets the height
    - Use ray instead of gpu_ray in the xacro source, as in the URDFs
    - hero.urdf and hero_laser.urdf: gazebo_ros_control removed as well
2026-10-17 Add collision element to cylinder_target so ray sensors detect it
2026-10-17 README: replace missing hero_spawn.launch, list sensors per URDF

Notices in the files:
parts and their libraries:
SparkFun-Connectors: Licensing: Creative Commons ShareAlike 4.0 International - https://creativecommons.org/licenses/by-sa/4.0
